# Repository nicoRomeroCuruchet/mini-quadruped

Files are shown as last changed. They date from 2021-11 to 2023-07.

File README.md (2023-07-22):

# Mini-Quadruped

This open-source project is designed for anyone interested in researching low-cost quadruped robotic platforms. It's built using the **Jetson Nano board** and the MCU **STM32F103C8T6**. By combining the equations for a rigid body rotations with leg inverse kinematics, I've developed an algorithm that accurately positions the multi-joint legs based on the orientation of the torso. With the incorporation of a gyroscope and accelerometer (MPU6050), and by fusing both measures, I'm able to obtain real-time information about the body's orientation. Additionally, I'm using a webcam to collect more data, which enables me to track hand movements.

**Here's a really funny gif of my new pet following my hand for you all!**

Demo

# Youtube video

https://youtu.be/wdcIH24sI44

https://youtu.be/hFUbpantrfs

# Jetno Nano 

Jetson Nano is a small, powerful, and low-cost computer developed by NVIDIA, designed for building AI applications and projects. It features a quad-core ARM Cortex-A57 CPU, a 128-core NVIDIA Maxwell GPU, and 4GB of LPDDR4 memory. The Jetson Nano also includes a variety of I/O ports, including USB 3.0, HDMI, Gigabit Ethernet, and GPIO, making it easy to interface with various devices and sensors.

The Jetson Nano runs on a Linux-based operating system and supports a variety of popular machine learning frameworks, including TensorFlow, PyTorch, and MXNet. It can be used for a wide range of AI applications, such as object detection, image classification, natural language processing, and robotics. Its compact size and low power consumption make it ideal for building portable and embedded AI systems.

A hand tracking solution that can detect and track the position and movement of hands in real-time video was designed using **MediaPipe**, which is an open-source framework developed by Google that provides a variety of pre-built, customizable machine learning models and processing pipelines for tasks such as image and video analysis, facial recognition, hand tracking, and more. MediaPipe also provides a set of C++ and Python libraries for developers to easily incorporate these models and pipelines into their own applications.

# STM32F103C8, "the Blue Pill"

The STM32F103C8 is a popular microcontroller from STMicroelectronics, based on the ARM Cortex-M3 core. It features 64 KB of Flash memory and 20 KB of SRAM, as well as a variety of on-chip peripherals, such as timers, SPI, I2C, USART, and ADC. The STM32F103C8 is commonly used in a wide range of embedded systems, including industrial control systems, motor control applications, and consumer electronics. Its high-performance, low-power consumption, and rich set of features make it a popular choice for developers looking to build complex and efficient systems. The STM32F103C8 is also supported by a variety of development tools and software, including the STM32CubeMX software tool, which allows developers to configure and generate code for the microcontroller.

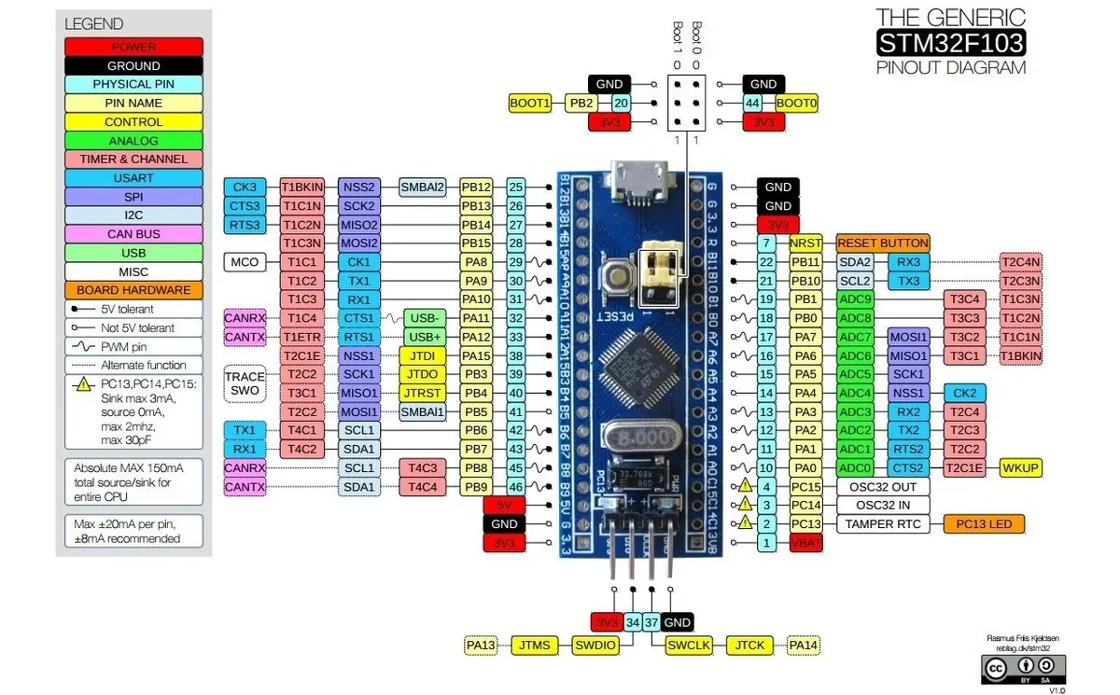
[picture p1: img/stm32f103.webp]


# How to deploy the code in the MCU?

The STM32CubeIDE is an advanced C/C++ development platform with peripheral configuration, code generation, code compilation,
and debug features for STM32 microcontrollers and microprocessors. Is available for free for different operating systems at 
the following link: 

      https://www.st.com/en/development-tools/stm32cubeide.html  

The **src** directory contains the code that should be executed with the STM32CubeIDE and deployed on the blue pill (STM32F103C8T6).
Run STM32CubeIDE, go to **File -> Import**, pull down the tab **'General'**, select **'Project from Folder or Archive'** and click next. 
Finally, **choose the path of src** where you have cloned in your pc.

In src/Core/Src/ (source file) and src/Core/Inc/ (header file) in this directory there are three files:

- **main**               : contains the main loop of the program that performs quadruped stabilization.
- **inverse_kinematics** : the functions to determine the motion of a quadruped leg to reach a desired position
- **MPU6050**            : contains the driver to handle the gyroscope and accelerometer, and combine them. Also implements **Kalman's algorithm** to filtering the measurements observed over time. The author of this library is **Bulanov Konstantin** (@leech001) and you can check out his github repo with this link https://github.com/leech001/MPU6050 

The **src/Core/Inc/servo_configuration.h** contains the setup to control the servos of each leg:

- **The Left Front Leg was handled via timer 1 channels 1, 2, 4**
- **The Left Rear Leg was handled via timer 3 channels 1, 3, 4**
- **The Right Front Leg was handled via timer 1 and 2. Timer 2 channels 3, 4 and timer 1 channel 3**
- **The Right Rear Leg was handled via timer 2 and 3. Timer 2 channel 1, 2 and timer 3 channel 2**

 and the file in src/mini-quadruped.ioc cotains the setup of the microcontroller it, can be accessed via the STM32CubeIDE:
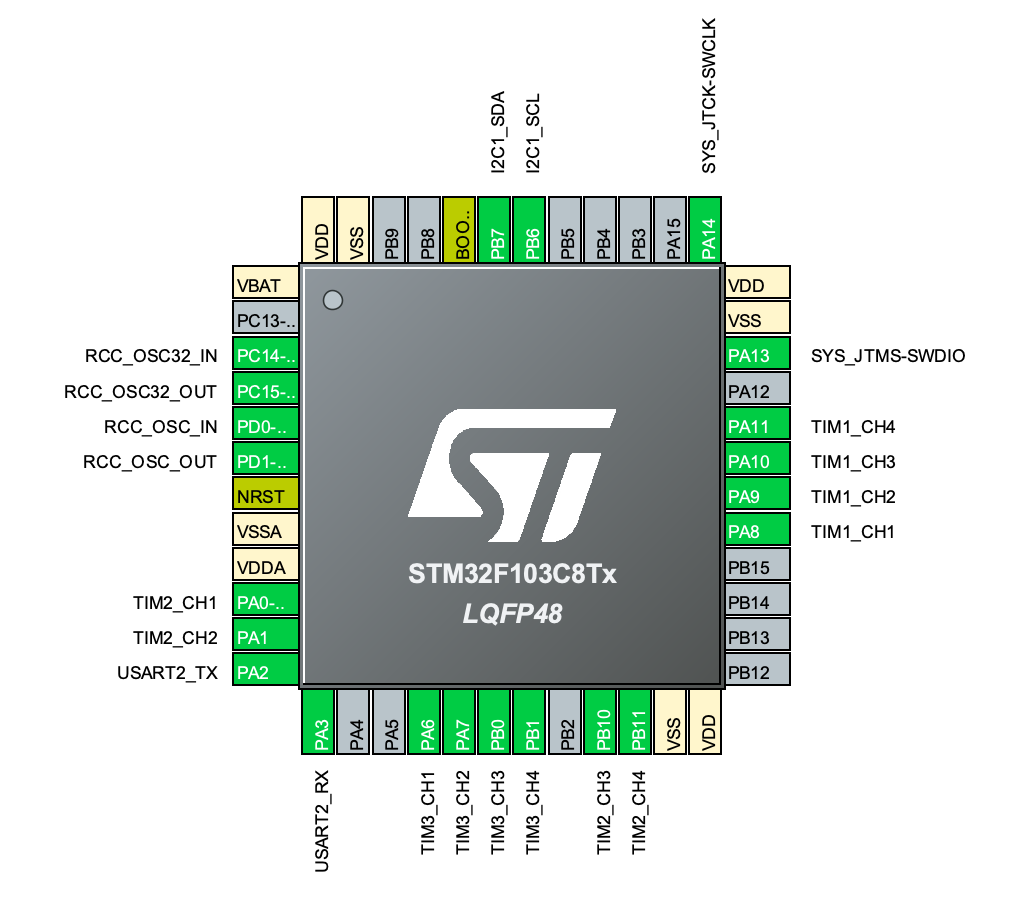
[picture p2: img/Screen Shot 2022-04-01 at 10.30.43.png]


# Jeton Nano and Blue Pill conection

Once the information is collected by the webcam and processed using the Mediapipe libraries running on the Jetson Nano, it's sent via USART (using Port A pins 2 and 3) to the Blue Pill. The Blue Pill then computes an algorithm to determine the position of the torso that's needed to center the hand in the image captured by the webcam, based on the hand's location on the screen.

The code that runs on the Jetson Nano can be found in the **mini-quadruped/mediapipe/webcam.py** file. After downloading the code onto the blue pill and testing the connection between the Jetson Nano and the MCU, execute the following command to start running the libraries that obtain the hand's position:

      python webcam.py
      
# MPU6050

The MPU6050 measures rotational and linear motion, and provides accurate data about the quadruped's orientation and movement. It communicates with the host device using I2C interface and can be easily integrated into a variety of microcontroller-based projects. In this project, I am using I2C1, which is located on the port B pins 6 and 7 of the MCU, and handle with the library probided by **Bulanov Konstantin**.

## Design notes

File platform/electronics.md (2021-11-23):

The electronic components that make up the platform that was investigated in this project are the following:

- 5A XL4005 DC-DC Adjustable Step Down Module Power Supply Converter          x 2    
- MPU6050                                                                     x 1
- Servo Afrc D2307HC 7.5kg                                                    x 12
- STM32F103C8T6 Blue Pill Development Board                                   x 1
- NVIDIA Jetson Nano                                                          x 1
- Experimental board (20 mm x 80 mm)                                          x 2

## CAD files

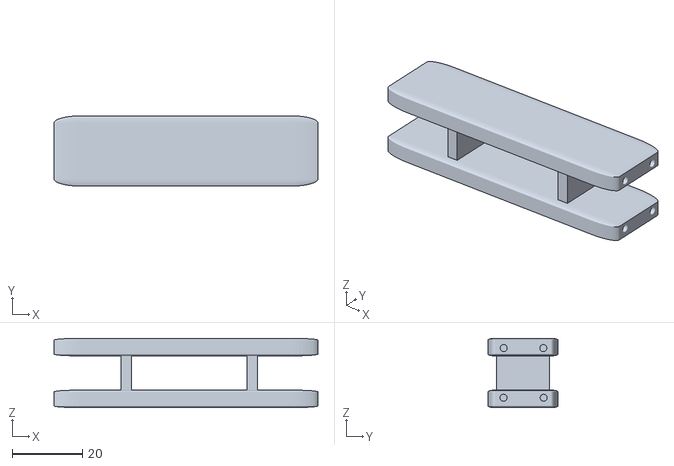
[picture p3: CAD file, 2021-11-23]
platform/chasis/rear_base_v1.stl
75.0 x 20.0 x 19.7

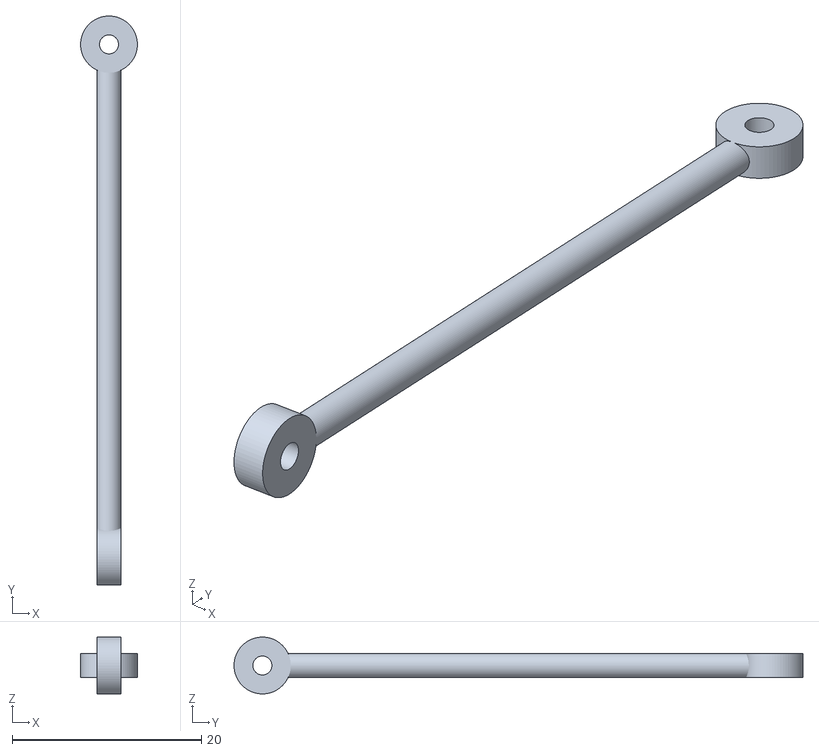
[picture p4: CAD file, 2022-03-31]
platform/Left_front_leg/links_v2.stl
6.00 x 60.1 x 6.00

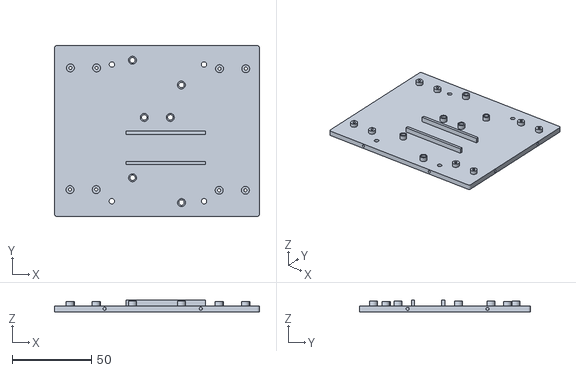
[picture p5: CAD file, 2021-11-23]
platform/chasis/base_chasis_v1.stl
129.0 x 107.5 x 7.42

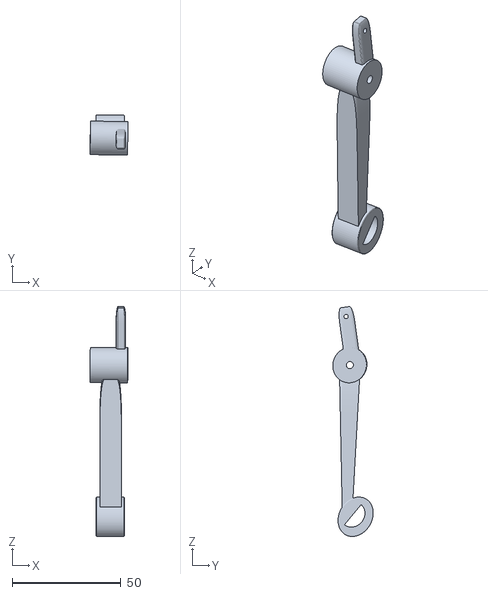
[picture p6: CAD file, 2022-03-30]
platform/Left_front_leg/left_tibia_v2.stl
17.5 x 18.6 x 105.9

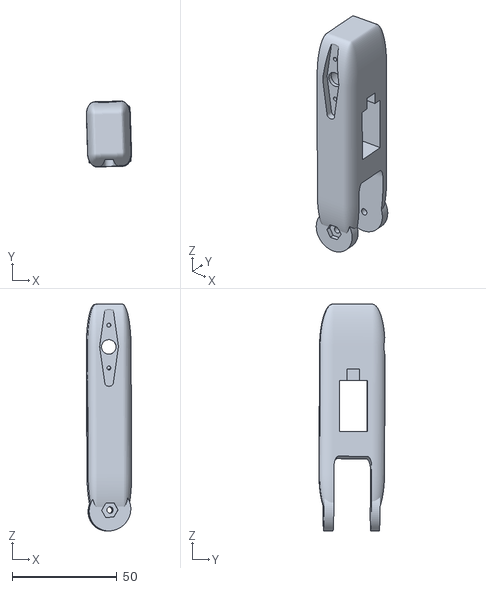
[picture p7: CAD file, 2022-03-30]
platform/Left_rear_leg/left_rear_femur_v2.stl
21.7 x 31.6 x 108.6

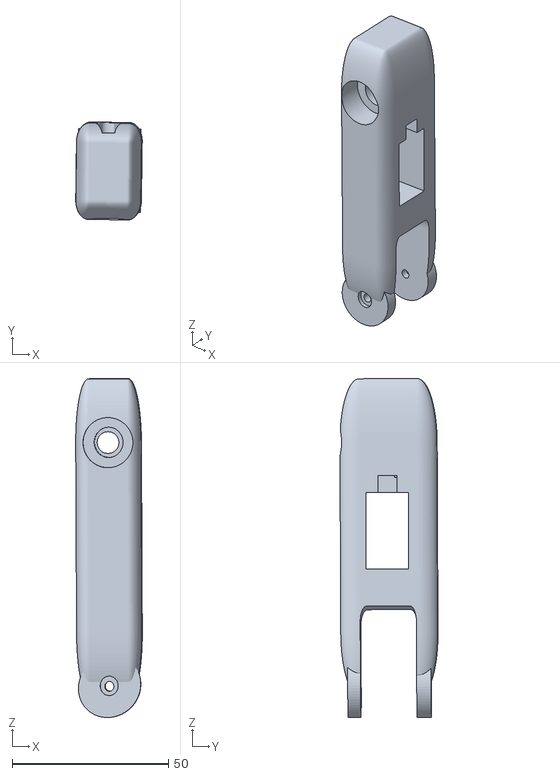
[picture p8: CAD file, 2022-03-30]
platform/Right_rear_leg/right_rear_femur_v2.stl
21.3 x 31.4 x 108.6

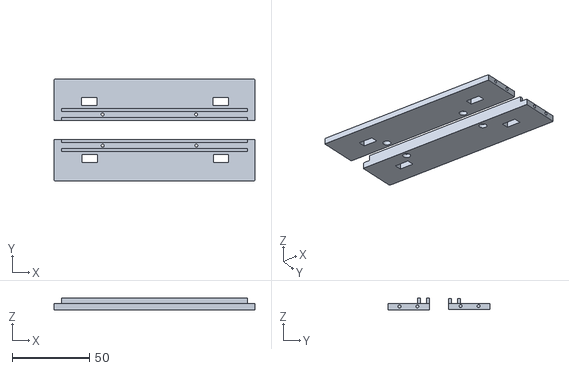
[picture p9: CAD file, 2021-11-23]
platform/chasis/side_chasis_v1.stl
130.0 x 66.0 x 7.60

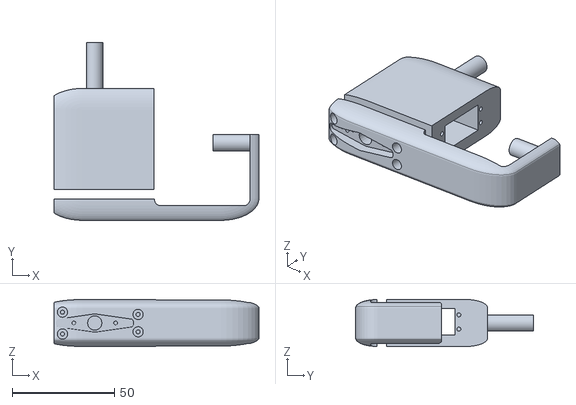
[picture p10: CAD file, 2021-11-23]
platform/Left_rear_leg/left_rear_coxa_v1.stl
100.3 x 87.0 x 23.0

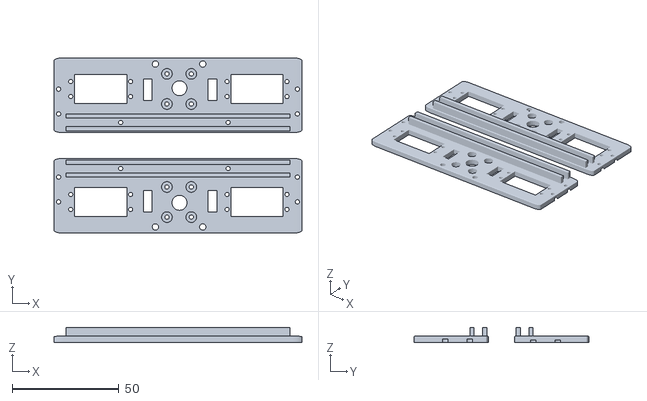
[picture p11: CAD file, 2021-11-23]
platform/chasis/front_rear_chasis_v1.stl
116.0 x 82.0 x 7.10

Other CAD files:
platform/Right_front_leg/right_front_tibia_v2.stl
platform/chasis/front_base_v1.stl
platform/Right_rear_leg/right_rear_tibia_v2.stl
platform/Left_front_leg/left_front_coxa_v1.stl
platform/Left_front_leg/left_front_femur_v1.stl
platform/Left_front_leg/links_v1.stl
platform/Left_rear_leg/left_rear_femur_v1.stl
platform/Left_rear_leg/links_v1.stl
platform/Right_front_leg/links_v1.stl
platform/Right_front_leg/right_front_coxa_v1.stl
platform/Right_front_leg/right_front_femur_v1.stl
platform/Right_rear_leg/links_v1.stl
platform/Right_rear_leg/right_rear_coxa_v1.stl
platform/Right_rear_leg/right_rear_femur_v1.stl
platform/chasis/front_v1.stl
platform/chasis/rear_v1.stl

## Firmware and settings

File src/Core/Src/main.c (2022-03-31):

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
/* Includes ------------------------------------------------------------------*/
#include "main.h"
#include "servo_configuration.h"
#include "mpu6050.h"
#include "inverse_kinematics.h"

/* USER CODE BEGIN Includes */
#include <math.h>
#include <stdlib.h>
#include <string.h>
/* USER CODE END Includes */

/* USER CODE BEGIN PD */

#define MIN(X, Y) (((X) < (Y)) ? (X) : (Y))
#define MAX(X, Y) (((X) > (Y)) ? (X) : (Y))


#define RAD_TO_DEG 	57.295779513082320876798154814105
#define PI 			3.141592653589793

#define L1  45
#define L2  78
#define L3  80

#define TRANSMITED_BYTES 15

#define MAX_PHI   0.4
#define MAX_PSI   0.35
#define MAX_THETA 0.35

#define PID_KALMAN_PSI   0.05
#define PID_KALMAN_THETA 0.05

#define torso_lenght 150
#define torso_width  90

/* USER CODE END PD */

I2C_HandleTypeDef hi2c1;

TIM_HandleTypeDef htim1;
TIM_HandleTypeDef htim2;
TIM_HandleTypeDef htim3;

UART_HandleTypeDef huart2;

/* USER CODE BEGIN PV */
uint8_t rx_buffer[TRANSMITED_BYTES] = {0,0,0,0,0,
									   0,0,0,0,0,
									   0,0,'x','x','x'};

/* USER CODE END PV */

void SystemClock_Config(void);
static void MX_GPIO_Init(void);
static void MX_TIM1_Init(void);
static void MX_TIM2_Init(void);
static void MX_TIM3_Init(void);
static void MX_I2C1_Init(void);
static void MX_USART2_UART_Init(void);
/**
  * @brief  The application entry point.
  * @retval int
  */
int main(void)
{
  /* MCU Configuration--------------------------------------------------------*/

  /* Reset of all peripherals, Initializes the Flash interface and the Systick. */
  HAL_Init();

  /* Configure the system clock */
  SystemClock_Config();

  /* Initialize all configured peripherals */
  MX_GPIO_Init();
  MX_TIM1_Init();
  MX_TIM2_Init();
  MX_TIM3_Init();
  MX_I2C1_Init();
  MX_USART2_UART_Init();
  /* USER CODE BEGIN 2 */
  HAL_TIM_PWM_Start(&htim1, TIM_CHANNEL_1);
  HAL_TIM_PWM_Start(&htim1, TIM_CHANNEL_2);
  HAL_TIM_PWM_Start(&htim1, TIM_CHANNEL_3);
  HAL_TIM_PWM_Start(&htim1, TIM_CHANNEL_4);

  HAL_TIM_PWM_Start(&htim2, TIM_CHANNEL_1);
  HAL_TIM_PWM_Start(&htim2, TIM_CHANNEL_2);
  HAL_TIM_PWM_Start(&htim2, TIM_CHANNEL_3);
  HAL_TIM_PWM_Start(&htim2, TIM_CHANNEL_4);

  HAL_TIM_PWM_Start(&htim3, TIM_CHANNEL_1);
  HAL_TIM_PWM_Start(&htim3, TIM_CHANNEL_2);
  HAL_TIM_PWM_Start(&htim3, TIM_CHANNEL_3);
  HAL_TIM_PWM_Start(&htim3, TIM_CHANNEL_4);

  HAL_UART_Receive_IT(&huart2, rx_buffer, TRANSMITED_BYTES);
  uint8_t res;

  do
  {
	res = MPU6050_Init(&hi2c1);
	if(res !=0)
	{
		HAL_Delay(500);
		HAL_I2C_DeInit(&hi2c1);  // reinitialize the I2C peripheral
		HAL_Delay(500);
		HAL_I2C_Init(&hi2c1);
	}

  } while(res != 0);

  MPU6050_t mpu;
  float distant_y = -70;
  /* Right Front Leg */
  float rf_r_m_o[3] = {torso_lenght * 0.5, 0.0, torso_width * 0.5};   			    // system o right front measure from m.
  float rf_m_l[3]   = {torso_lenght * 0.5 - 30, distant_y,  L1 + (torso_width * 0.5)};   // right front tip of the foot measure from m.
  /* Right Rear Leg */
  float rr_r_m_o[3] = {-torso_lenght * 0.5, 0.0, torso_width * 0.5};		        // system o right rear measure from m.
  float rr_m_l[3]   = {-20-torso_lenght * 0.5, distant_y,  L1 + (torso_width * 0.5)};  // right rear tip of the foot measure from m.
  /* Left Front Leg */
  float lf_r_m_o[3] = {torso_lenght * 0.5, 0.0, -torso_width*0.5};                  // system o left front measure from m.
  float lf_m_l[3]   = {torso_lenght * 0.5 - 30, distant_y, -L1 - (torso_width*0.5)};     // left front tip of the foot measure from m.
  /* Left Rear Leg */
  float lr_r_m_o[3] = {-torso_lenght*0.5, 0.0, -torso_width*0.5};				    // system o left rear measure from m.
  float lr_m_l[3]   = {-20-torso_lenght*0.5, distant_y, -L1 - (torso_width*0.5)};	    // left rear tip of the foot measure from m.

  float rf_ik_res[3];
  float rf_rotated[3];
  float rf_r_o_rot[3];

  float rr_ik_res[3];
  float rr_rotated[3];
  float rr_r_o_rot[3];

  float lf_ik_res[3];
  float lf_rotated[3];
  float lf_r_o_rot[3];

  float lr_ik_res[3];
  float lr_rotated[3];
  float lr_r_o_rot[3];

  float T[3] = {0,10.0,0};
  float psi   = 0.0;   // Rot Z
  float phi   = 0.0;   // Rot Y
  float theta = 0.0;   // Rot X

  float error_psi;
  float set_point_psi = 0.0;
  float error_theta;
  float set_point_theta = 0.0;
  float error_phi = 0.0;
  float error_phi_prev = 0.0;
  char phi_buffer[5] = {0,0,0,0,0};
  char psi_buffer[5] = {0,0,0,0,0};

  /* USER CODE BEGIN WHILE */
  while (1)
  {
    /* USER CODE END WHILE */
    /* USER CODE BEGIN 3 */
	if (rx_buffer[12] == 'x' &&
		rx_buffer[13] == 'x' &&
		rx_buffer[14] == 'x')
	{
		MPU6050_Read_All(&hi2c1, &mpu);

		error_psi   = set_point_psi     - ((mpu.KalmanAngleX)*PI/180);
		error_theta = set_point_theta   - ((mpu.KalmanAngleY)*PI/180);

		psi   += PID_KALMAN_PSI*error_psi;
		theta += PID_KALMAN_THETA*error_theta;
		phi = phi*0.97;
	}
	else
	{

		for(int i=0; i<5; ++i)
		{
			phi_buffer[i] = rx_buffer[i];
			psi_buffer[i] = rx_buffer[i+5];
		}

		error_phi = (float)(atof(phi_buffer));
		error_psi = (float)(atof(psi_buffer));

		phi += 0.08*error_phi + 0.002*(error_phi - error_phi_prev);
		error_phi_prev = error_phi;
		psi += 0.04*error_psi;
	}

	// limits
	if(phi >  MAX_PHI)      phi   =  MAX_PHI;
	if(phi < -MAX_PHI)      phi   = -MAX_PHI;

	if(psi >  MAX_PSI)      psi   =  MAX_PSI;
	if(psi < -MAX_PSI)      psi   = -MAX_PSI;

	if(theta >  MAX_THETA)  theta =  MAX_THETA;
	if(theta < -MAX_THETA)  theta = -MAX_THETA;

	/* 1 - Right Front */
	roto_translation(psi, phi, theta, T, rf_r_m_o, rf_rotated);
	subtract(rf_m_l, rf_rotated, rf_r_o_rot);
	inverse_kinematics(rf_r_o_rot, L1, L2, L3,'r', rf_ik_res);
	/* 2 - Right Rear */
	roto_translation(psi, phi, theta, T, rr_r_m_o, rr_rotated);
	subtract(rr_m_l, rr_rotated, rr_r_o_rot);
	inverse_kinematics(rr_r_o_rot, L1, L2, L3,'r', rr_ik_res);
	/* 3 - Left Front */
	roto_translation(psi, phi, theta, T, lf_r_m_o, lf_rotated);
	subtract(lf_m_l, lf_rotated, lf_r_o_rot);
	inverse_kinematics(lf_r_o_rot, L1, L2, L3,'l', lf_ik_res);
	/* 4 - Left Rear */
	roto_translation(psi, phi, theta, T, lr_r_m_o, lr_rotated);
	subtract(lr_m_l, lr_rotated, lr_r_o_rot);
	inverse_kinematics(lr_r_o_rot, L1, L2, L3,'l', lr_ik_res);

	LR_servo_ii  = round(MAX(MIN(LR_a_servo_ii*lr_ik_res[1]  + LR_b_servo_ii,  MAX_LR_servo_ii),  MIN_LR_servo_ii));
	LR_servo_iii = round(MAX(MIN(LR_a_servo_iii*lr_ik_res[2] + LR_b_servo_iii, MAX_LR_servo_iii), MIN_LR_servo_iii));
	LR_servo_i   = round(MAX(MIN(LR_a_servo_i*lr_ik_res[0]   + LR_b_servo_i,   MAX_LR_servo_i),   MIN_LR_servo_i));

	LF_servo_ii  = round(MAX(MIN(LF_a_servo_ii*lf_ik_res[1]  + LF_b_servo_ii,  MAX_LF_servo_ii),  MIN_LF_servo_ii));
	LF_servo_iii = round(MAX(MIN(LF_a_servo_iii*lf_ik_res[2] + LF_b_servo_iii, MAX_LF_servo_iii), MIN_LF_servo_iii));
	LF_servo_i   = round(MAX(MIN(LF_a_servo_i*lf_ik_res[0]   + LF_b_servo_i,   MAX_LF_servo_i),   MIN_LF_servo_i));

	RR_servo_ii  = round(MAX(MIN(RR_a_servo_ii*rr_ik_res[1]  + RR_b_servo_ii,  MAX_RR_servo_ii),  MIN_RR_servo_ii));
	RR_servo_iii = round(MAX(MIN(RR_a_servo_iii*rr_ik_res[2] + RR_b_servo_iii, MAX_RR_servo_iii), MIN_RR_servo_iii));
	RR_servo_i   = round(MAX(MIN(RR_a_servo_i*rr_ik_res[0]   + RR_b_servo_i,   MAX_RR_servo_i),   MIN_RR_servo_i));

	RF_servo_ii  = round(MAX(MIN(RF_a_servo_ii*rf_ik_res[1]  + RF_b_servo_ii,  MAX_RF_servo_ii),  MIN_RF_servo_ii));
	RF_servo_iii = round(MAX(MIN(RF_a_servo_iii*rf_ik_res[2] + RF_b_servo_iii, MAX_RF_servo_iii), MIN_RF_servo_iii));
	RF_servo_i   = round(MAX(MIN(RF_a_servo_i*rf_ik_res[0]   + RF_b_servo_i,   MAX_RF_servo_i),   MIN_RF_servo_i));
  }
  /* USER CODE END 3 */
}

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
/* USER CODE BEGIN 4 */
void HAL_UART_RxCpltCallback(UART_HandleTypeDef *huart)
{
	HAL_UART_Receive_IT(&huart2, rx_buffer, TRANSMITED_BYTES);
}

void HAL_UART_TxCpltCallback(UART_HandleTypeDef* huart)
{

	__NOP();

}
/* USER CODE END 4 */
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


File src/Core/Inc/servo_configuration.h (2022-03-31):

/*
 * servo_configurations.h
 *
 *  Created on: Mar 30, 2022
 *      Author: nicoromerocuruchet
 */

#ifndef INC_SERVO_CONFIGURATION_H_
#define INC_SERVO_CONFIGURATION_H_

/* Left Front Leg */
#define LF_a_servo_i  584.09839082
#define LF_b_servo_i  1465.0

#define LF_a_servo_ii  -627.07020704
#define LF_b_servo_ii  970

#define LF_a_servo_iii  949.2240125
#define LF_b_servo_iii  -25.43047706
// (i):
#define MAX_LF_servo_i 2000
#define MIN_LF_servo_i 1000
#define LF_servo_i   TIM1->CCR2
// (ii)
#define MAX_LF_servo_ii 2450
#define MIN_LF_servo_ii 550
#define LF_servo_ii  TIM1->CCR1
// (iii)
#define MAX_LF_servo_iii 2100
#define MIN_LF_servo_iii 900
#define LF_servo_iii TIM1->CCR4

/* Left Rear Leg */
#define LR_a_servo_i  -601.60542705
#define LR_b_servo_i  1425.0

#define LR_a_servo_ii  -604.78852455
#define LR_b_servo_ii  1050.0

#define LR_a_servo_iii 957.22527156
#define LR_b_servo_iii -114.77667663

// (i):
#define MAX_LR_servo_i 2000
#define MIN_LR_servo_i 1000
#define LR_servo_i   TIM3->CCR1
// (ii)
#define MAX_LR_servo_ii 2450
#define MIN_LR_servo_ii 600
#define LR_servo_ii  TIM3->CCR3
// (iii)
#define MAX_LR_servo_iii 2100
#define MIN_LR_servo_iii 1100
#define LR_servo_iii TIM3->CCR4

/* Right Front Leg */
#define RF_a_servo_i 598.42232956
#define RF_b_servo_i 1500.0

#define RF_a_servo_ii 601.60542705
#define RF_b_servo_ii 1985.0

#define RF_a_servo_iii  -990.64488319
#define RF_b_servo_iii  3088.20381872

// (i)
#define MAX_RF_servo_i 2000
#define MIN_RF_servo_i 1000
#define RF_servo_i  TIM2->CCR4
// (ii)
#define MAX_RF_servo_ii 2370
#define MIN_RF_servo_ii 600
#define RF_servo_ii TIM1->CCR3
//(iii)
#define MAX_RF_servo_iii 2100
#define MIN_RF_servo_iii 900
#define RF_servo_iii TIM2->CCR3

/* Right Rear Leg */
#define RR_a_servo_i -601.60542705
#define RR_b_servo_i 1473.33333333

#define RR_a_servo_ii  636.61949953
#define RR_b_servo_ii  2020.0

#define RR_a_servo_iii  -1053.44201921 //
#define RR_b_servo_iii  3297.69769341

// (i)
#define MAX_RR_servo_i 2000
#define MIN_RR_servo_i 1000
#define RR_servo_i   TIM2->CCR1
// (ii)
#define MAX_RR_servo_ii 2400
#define MIN_RR_servo_ii 600
#define RR_servo_ii  TIM3->CCR2
//(iii)
#define MAX_RR_servo_iii 2100
#define MIN_RR_servo_iii 900
#define RR_servo_iii TIM2->CCR2


#endif /* INC_SERVO_CONFIGURATION_H_ */

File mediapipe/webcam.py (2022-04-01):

import cv2
import time
import serial
import mediapipe as mp

cam = cv2.VideoCapture(0)
mpHands = mp.solutions.hands
hands = mpHands.Hands()
mpDraw = mp.solutions.drawing_utils

start = 0 
end = 0
num_of_bytes = 5

serial_port = serial.Serial(
    port="/dev/ttyUSB0",
    baudrate=115200,
    bytesize=serial.EIGHTBITS,
    parity=serial.PARITY_NONE,
    stopbits=serial.STOPBITS_ONE
    )

time.sleep(1)
r = 0
r_x = 0
r_y = 0 

a = True 
 
while True:
        _, img = cam.read()
        imgRGB = cv2.cvtColor(img, cv2.COLOR_BGR2RGB)
        results = hands.process(imgRGB)

        if results.multi_hand_landmarks:
                for handLms in results.multi_hand_landmarks:
                        for id, lm in enumerate(handLms.landmark):
                                
                                h,w,c = img.shape
                                cx, cy, cz = int(lm.x*w), int(lm.y*h), int(lm.z*h)

                                if id == 9: 
                                        r_x = -round(0.4*(cx - w/2)/w + 0.6*r_x, 2)
                                        r_y = -round(0.4*(cy - h/2)/h + 0.6*r_y, 2)
                                        data = str(r_x).zfill(num_of_bytes) + str(r_y).zfill(num_of_bytes) + str(int(r)).zfill(num_of_bytes)
                                        serial_port.write(data.encode())

                        mpDraw.draw_landmarks(img, handLms, mpHands.HAND_CONNECTIONS)
                        a=True

        else:
                if(a):
                        data = str('xxx').rjust(15, '0')
                        serial_port.write(data.encode())
                        
                a = False

        start = time.time()
        fps = 1 / (start - end)
        end = start
        cv2.putText(img,str(int(fps)), (10,70), cv2.FONT_HERSHEY_PLAIN, 3,(0,255,0),3)

        cv2.imshow('Webcam', img)
        if cv2.waitKey(1) == ord('q'):
                break

data = str('xxx').rjust(15, '0')
serial_port.write(data.encode())
time.sleep(1)
cam.release()
serial_port.close()
cv2.destroyAllWindows()

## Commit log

2021-11-23 The quadruped platform
    [base_chasis_v1.stl, front_base_v1.stl, front_chasis_v1.stl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]
2022-03-29 smt32 source quadruped code
    [mini-quadruped.cfg]
2022-03-29 change places .stl files
    [base_chasis_v1.stl, front_chasis_v1.stl, side_chasis_v1.stl]
2022-03-29 rename files
    [front_rear_chasis_v1.stl]
2022-03-30 latest design version
    [front_base_v1.stl, front_chasis_v1.stl, front_v1.stl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]
2022-03-30 delte files
    [front_base_v1.stl]
2022-03-31 new links version
    [links_v2.stl]
2022-03-31 servo parameters for configurations
2022-03-31 inverse kinematics functions
2022-04-01 img stm32
2022-04-01 Jetson nano file Hand Tracking via media pipe

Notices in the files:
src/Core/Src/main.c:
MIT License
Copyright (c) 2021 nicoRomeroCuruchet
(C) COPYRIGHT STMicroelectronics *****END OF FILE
